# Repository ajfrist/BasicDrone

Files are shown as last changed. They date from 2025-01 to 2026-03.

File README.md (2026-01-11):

# BasicDrone Project

This is a custom-designed Arduino-based drone and controller system that uses a LoRa transceiver for reliable communication. The project includes 3D printed components modeled in Blender and a custom software sketches.

## 🚀 **Project Overview**

This project aims to create an affordable, modular, and easy-to-build drone system. The drone is powered by an Arduino Nano, while the controller uses an Arduino Uno for flight control. Communication between the drone and the controller is handled by a robust LoRa transceiver.

### **Features**
- Arduino Nano-based drone with custom code for optimal motor control and sensor integration.
- Arduino Uno-based controller for user-friendly flight controls.
- LoRa transceiver for long-range wireless communication.
- Blender-designed 3D printed parts for lightweight and customizable drone assembly.

## 🛠️ **Parts List**

### **Drone:**
- Arduino Nano
- LoRa SX1276 transceiver module
- EMAX RS2205 2300kv brushless motor (x4)
- BLHeli LittleBee Electronic Speed Controllers (ESCs) (x4)
- 5' Propellers (x4)
- 3D printed frame components
- Ovonic 3S 50C 2200mAh 11.1V LiPo Battery 
- GY-521 MPU-6050 Gyroscope & Accelerometer
- ArduCAM-2MP-Plus B0067
- Misc: wires, heat shrink tubing

### **Controller:**
- Arduino Uno
- LoRa SX1276 transceiver module 
- Joystick modules (x2)
- Misc: push buttons, resistors, LEDs, wires

## 🧩 **CAD Design & Prototyping**

All 3D models for this project were designed in **Blender**, with an emphasis on simplicity and structural integrity. The designs are optimized for 3D printing using widely accessible filament-based printers. 

### **Prototype Images:**
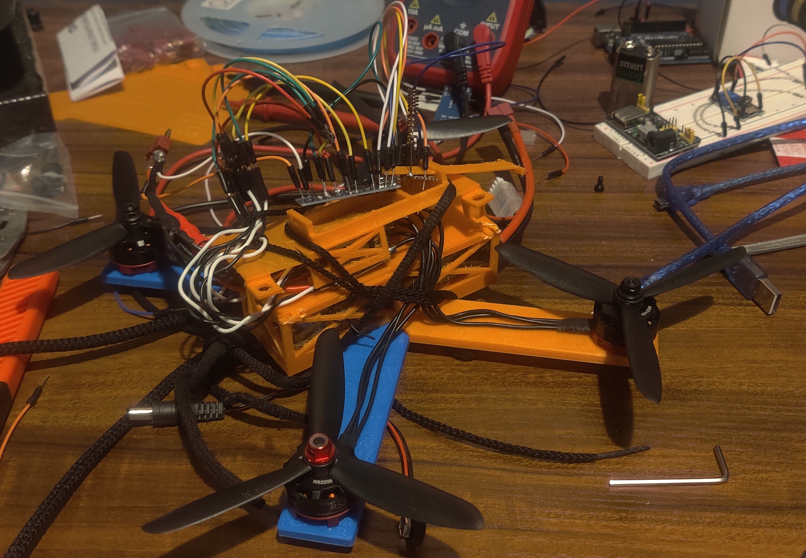
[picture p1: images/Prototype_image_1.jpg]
Prototype Image
**

## ✍️ **Schematics**

The schematics for the drone and the controller detail the electrical connections, ensuring you can replicate the design accurately. 

### Drone
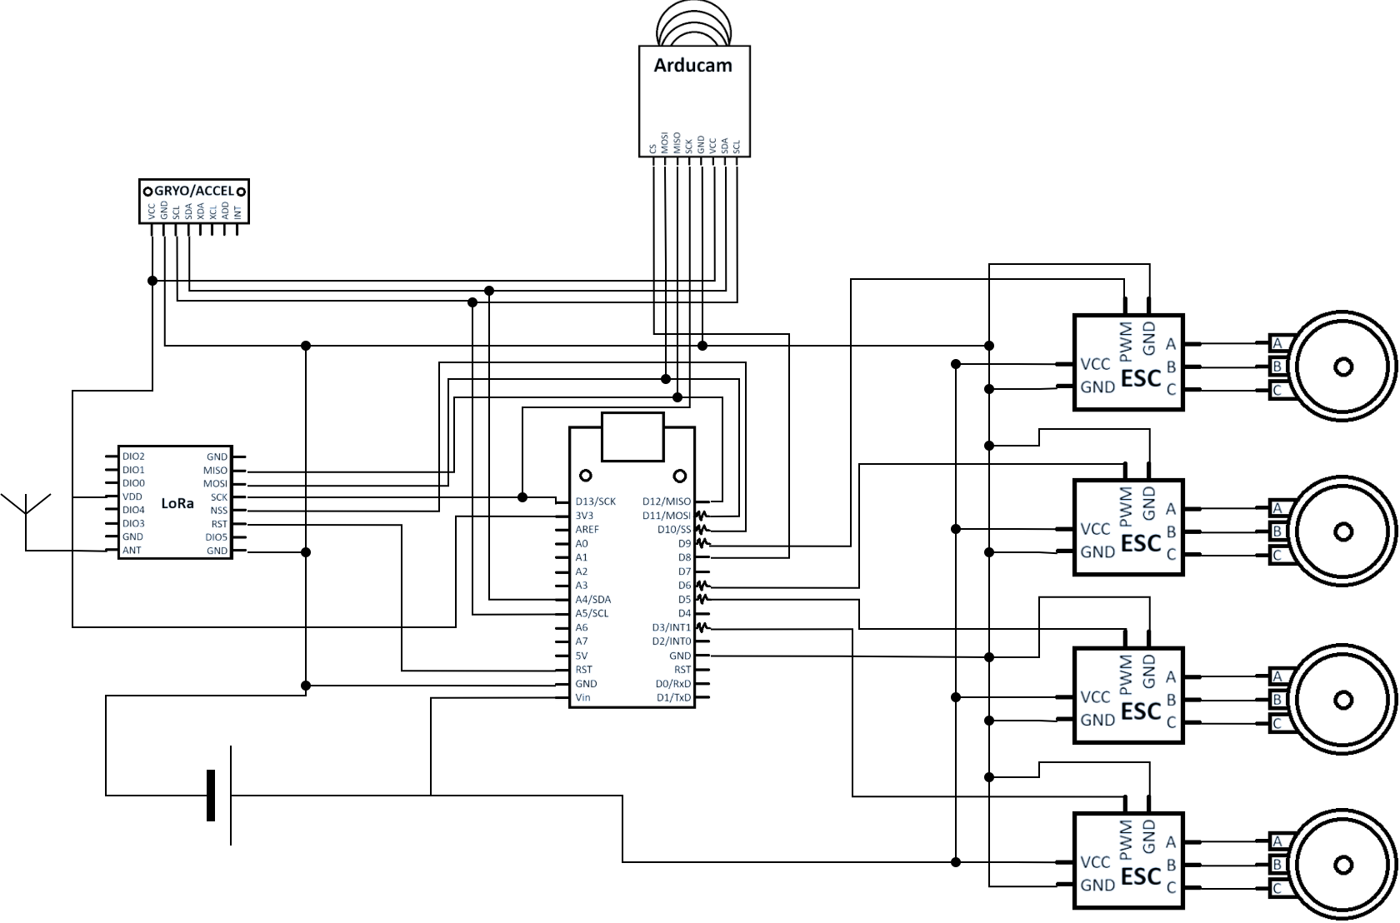
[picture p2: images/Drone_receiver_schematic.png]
Receiver Schematic Image
**

### Controller
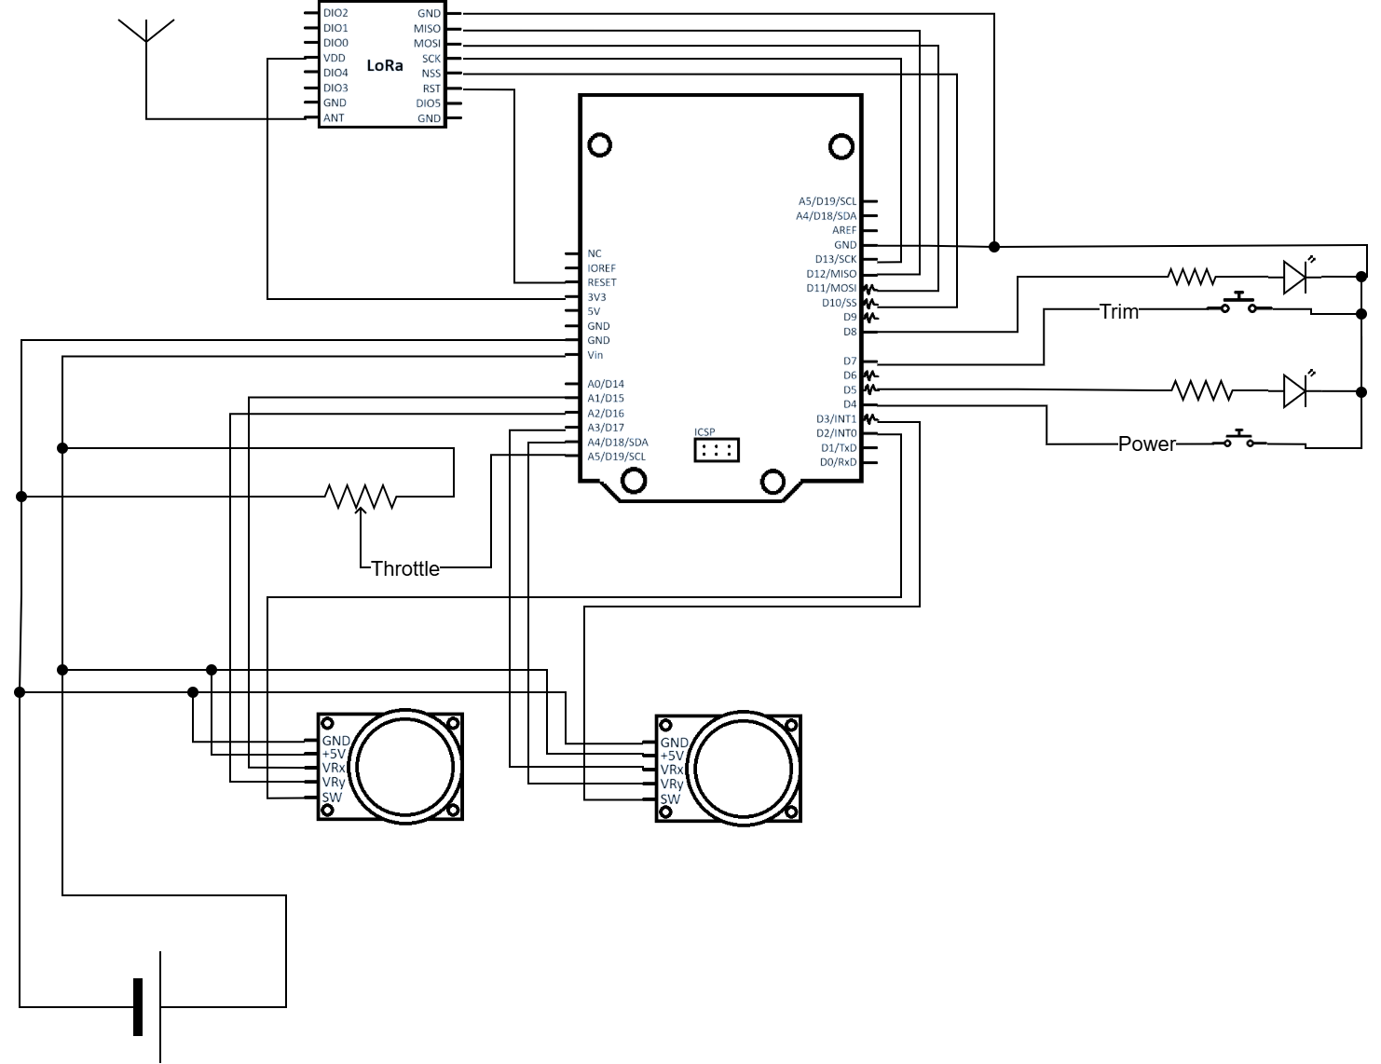
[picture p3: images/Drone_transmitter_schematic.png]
Transmitter Schematic Image
**

## 🎯 **Getting Started**

1. Install the Arduino IDE for uploading the custom code to the boards.
2. Have Blender or another CAD software installed if you wish to modify or customize the 3D models.
3. Ensure access to a 3D printer for building the mechanical components.
4. Total printed items includes:
    - Drone top & bottom
    - 4x pins
    - 2x each of Left/Right Wings (for front and back)
    - Securing bar for Ardunio Nano
5. Flash Arduino Uno with the `drone_transmitter_post` sketch and Arduino Nano with the `drone_receiver_post` sketch.

## 📜 **License**
This project is licensed under the MIT License - see the [LICENSE](LICENSE) file for details.

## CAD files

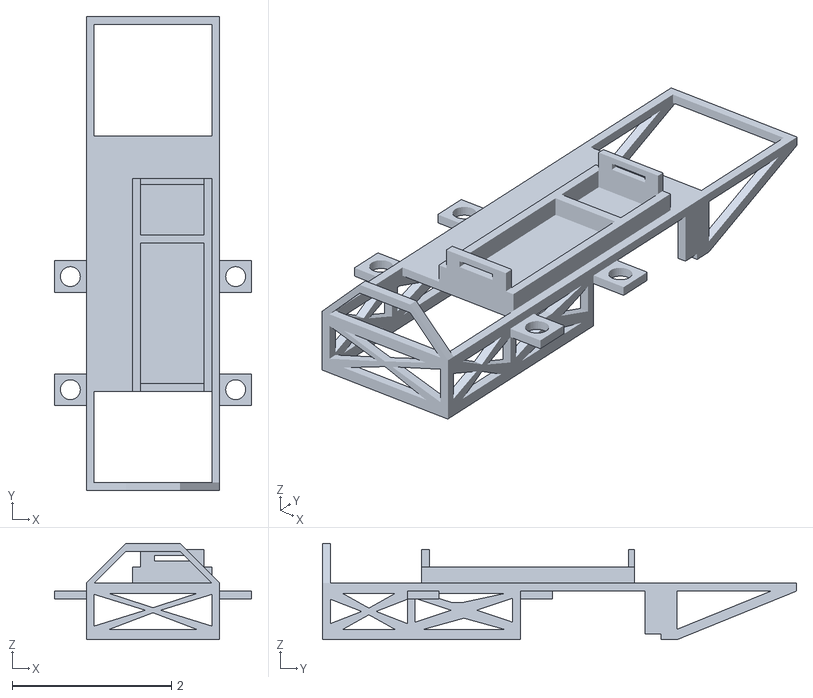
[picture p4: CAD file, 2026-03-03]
stl/Drone_Case_Top.stl
2.48 x 5.95 x 1.21

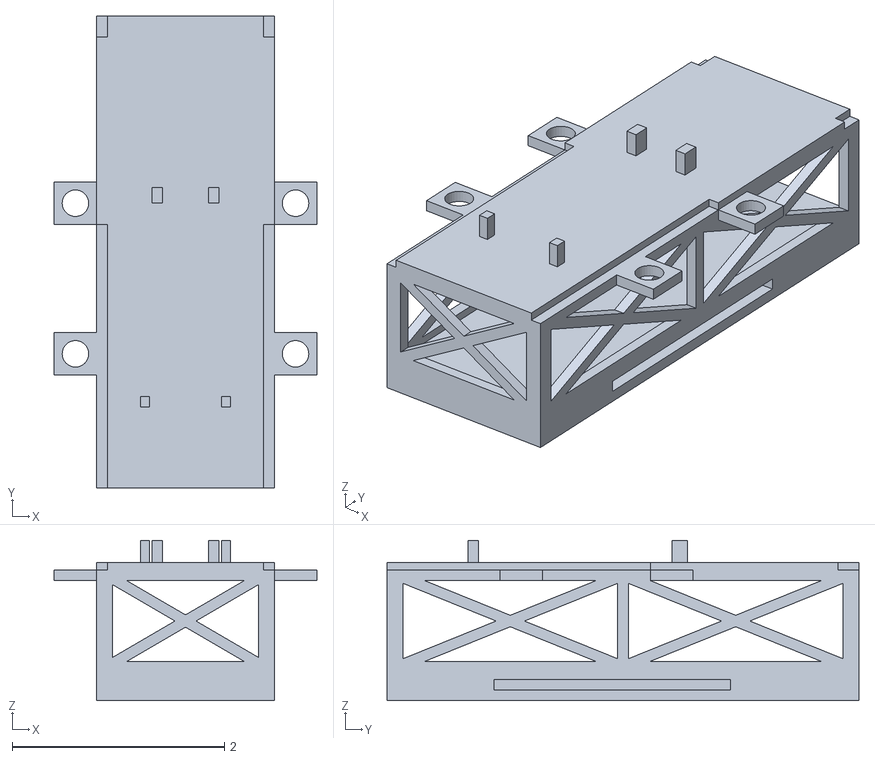
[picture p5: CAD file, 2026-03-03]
stl/Drone_Case_Bottom.stl
2.48 x 4.45 x 1.51

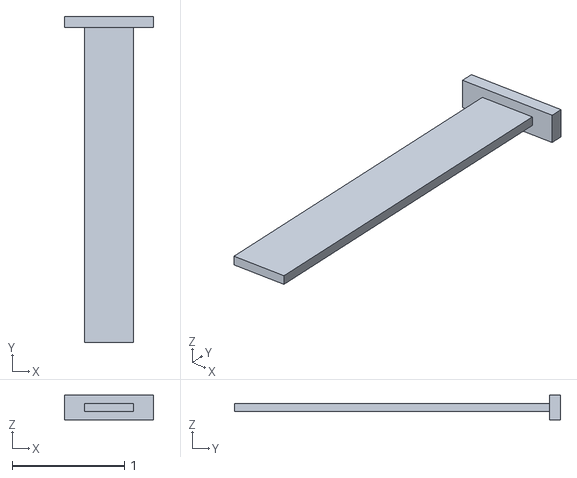
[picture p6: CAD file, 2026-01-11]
stl/Top_Secure.stl
0.792 x 2.91 x 0.219

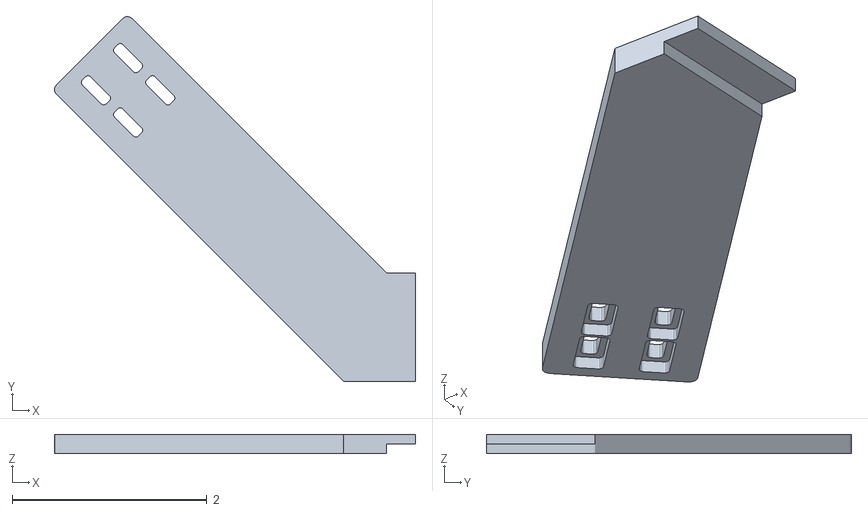
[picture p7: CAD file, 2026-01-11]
stl/Wing_FL.stl
3.71 x 3.75 x 0.2

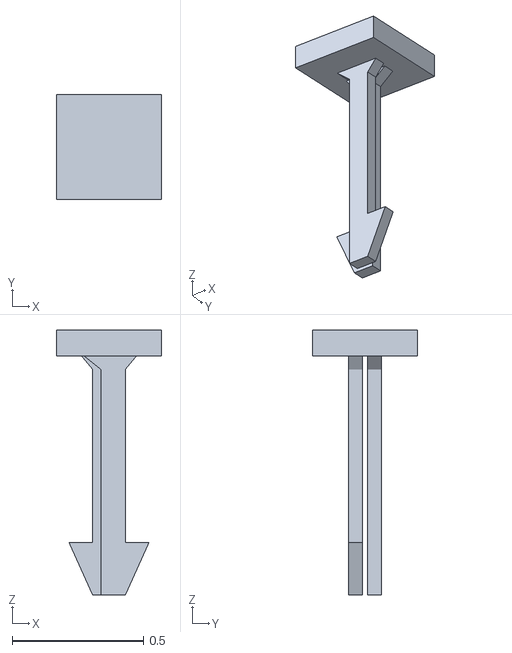
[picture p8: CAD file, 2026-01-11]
stl/Pin_Clip_1.stl
0.4 x 0.4 x 1.01

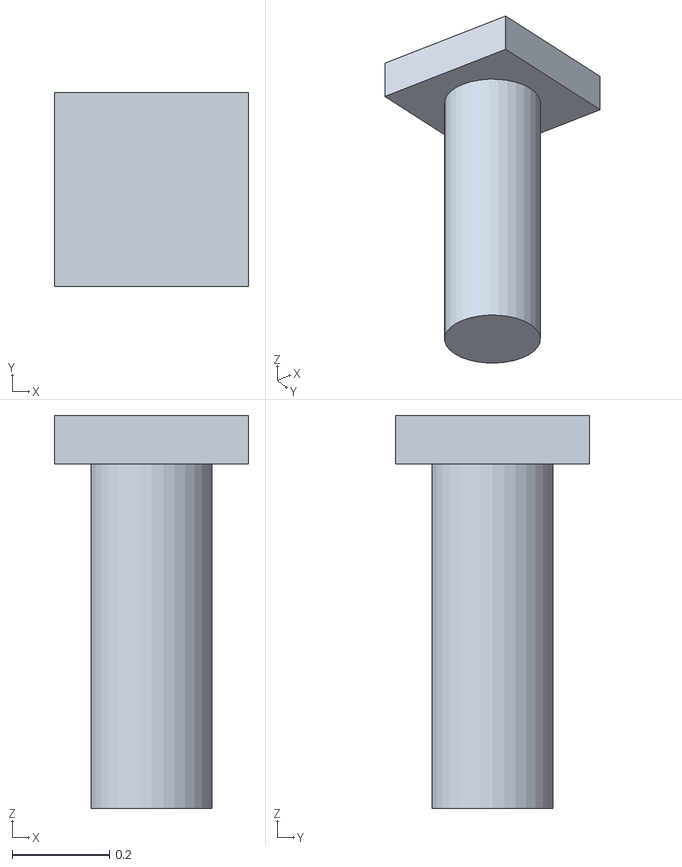
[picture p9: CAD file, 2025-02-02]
stl/Pin_1.stl
0.4 x 0.4 x 0.81

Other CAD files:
stl/Wing_FR.stl
drone_body.blend

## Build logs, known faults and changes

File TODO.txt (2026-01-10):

move inward the vertical supporters
need 4 bars, not two
loop on top front & top back for feeding wire through to prevent falling into side props
side guard not aligned
screw holes - not long enough, too deep

screw measures: 
thread lentgh: .230
thread width: .115
head width .210
head height: .114

screw hole scale x: 1.79167 times      \___ 0.0475 all direction, 0.095 per axis
 		y:  1.2375 times   /
vertically move screw head gap: .09 clearance on bottom, 0.11 rest through to top

Code: 
- transmitter/receiver: adjust LoRa transmit encoding to send using byte encoding not ASCII
- transmitter/receiver: add check bit to ensure packet clarity
- receiver: functionality to adjust movement scalers boundaries according to current trim 

- eventually encode/compress camera feed?

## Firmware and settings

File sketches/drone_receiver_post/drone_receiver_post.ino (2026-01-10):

#include <Servo.h>
#include <SPI.h>
#include <LoRa.h>
// #include <Wire.h> // used for all I2C devices

#define DEBUG 1  // Set to 1 to enable debug prints
#if DEBUG
  #define DEBUG_PRINT(x)    Serial.print(x)
  #define DEBUG_PRINTLN(x)  Serial.println(x)
#else
  #define DEBUG_PRINT(x)    do {} while (0)
  #define DEBUG_PRINTLN(x)  do {} while (0)
#endif

// Memory checking function
#ifdef __arm__
// should use uinstd.h to define sbrk but Due causes a conflict
extern "C" char* sbrk(int incr);
#else  // __ARM__
extern char *__brkval;
#endif  // __arm__

int freeMemory() {
  char top;
#ifdef __arm__
  return &top - reinterpret_cast<char*>(sbrk(0));
#elif defined(CORE_TEENSY) || (ARDUINO > 103 && ARDUINO != 151)
  return &top - __brkval;
#else  // __arm__
  return __brkval ? &top - __brkval : &top - __malloc_heap_start;
#endif  // __arm__
}


double applyDeadzone(int value, int deadzone_radius = 5);

// const int MPU_ADDR = 0x68; // I2C address of the MPU-6050. If AD0 pin is set to HIGH, the I2C address will be 0x69.
// int16_t accelerometer_x, accelerometer_y, accelerometer_z; // variables for accelerometer raw data
// int16_t gyro_x, gyro_y, gyro_z; // variables for gyro raw data
// int16_t temperature; // variables for temperature data
// char tmp_str[7]; // temporary variable used in convert function - used to output data to serial console
// char* convert_int16_to_str(int16_t i) { // converts int16 to string. Moreover, resulting strings will have the same length in the debug monitor.
//   sprintf(tmp_str, "%6d", i);
//   return tmp_str;
// }

Servo motor1;
Servo motor2;
Servo motor3;
Servo motor4;

// int MOTOR_PIN_1 = 1;
// int MOTOR_PIN_2 = 9;
// int MOTOR_PIN_3 = 10;
// int MOTOR_PIN_4 = 13;
const int MOTOR_PIN_1 = 3;
const int MOTOR_PIN_2 = 5;
const int MOTOR_PIN_3 = 6;
const int MOTOR_PIN_4 = 9;


/**
Motor microsecond active value ranges (low/off -> high/max power): 
motor1: ~1100-1900
motor2: ~1100-1900
motor3: ~1100-1900
motor4: ~1100-1900

DEFAULT -> 1000 = OFF
*/

//FIX BASED ON TUNING
// Default, idle (balanced) speeds
const int MOTOR_POWER_1 = 1300;
const int MOTOR_POWER_2 = 1300;
const int MOTOR_POWER_3 = 1300;
const int MOTOR_POWER_4 = 1300;

// State trim settings
int motor_trim_1 = 0;
int motor_trim_2 = 0;
int motor_trim_3 = 0;
int motor_trim_4 = 0;

// Used if lost packet or signal
double last_power1 = MOTOR_POWER_1;
double last_power2 = MOTOR_POWER_2;
double last_power3 = MOTOR_POWER_3;
double last_power4 = MOTOR_POWER_4;
int isOn = 0;


/*
 Motor Configuration:
 2 3
 1 4
 CCW CW
 CW  CCW

 Motor 1: Rear left CW
 Motor 2: Front left CCW
 Motor 3: Front right CW
 Motor 4: Rear right CCW
 */

// Set max bounding for motor movements; keeps joystick values within ms domain
const double THRUST_SCALER = 0.5;
const double FORWARD_MOVEMENT_SCALER = 0.5;
const double SIDE_MOVEMENT_SCALER = 0.5;
const double ROTATION_SCALER = 0.5;


void setup() {
  Serial.begin(9600);
  motor1.attach(MOTOR_PIN_1);
  motor1.writeMicroseconds(1000);
  motor2.attach(MOTOR_PIN_2);
  motor2.writeMicroseconds(1000);
  motor3.attach(MOTOR_PIN_3);
  motor3.writeMicroseconds(1000);
  motor4.attach(MOTOR_PIN_4);
  motor4.writeMicroseconds(1000);

  while (!Serial);
  DEBUG_PRINTLN("LoRa Receiver");
  if (!LoRa.begin(915E6)) {
    DEBUG_PRINTLN("Starting Lora failed!");
    while (1);
  }

  LoRa.receive();

  // // Setup for GY-521 Gyro/Accelerometer
  // Wire.begin();
  // Wire.beginTransmission(MPU_ADDR); // Begins a transmission to the I2C slave (GY-521 board)
  // Wire.write(0x6B); // PWR_MGMT_1 register
  // Wire.write(0); // set to zero (wakes up the MPU-6050)
  // Wire.endTransmission(true);

  delay(15000);
}

void loop() {
  DEBUG_PRINT("Free memory: ");
  DEBUG_PRINTLN(freeMemory());
  // int throttle = (int) LoRa.read();
  // int trimToggle = (int) LoRa.read();
  // int switch2 = (int) LoRa.read();
  // int x1 = (int) LoRa.read();
  // int y1 = (int) LoRa.read();
  // int x2 = (int) LoRa.read();
  // int y2 = (int) LoRa.read();
  int throttle = -1;
  int trimToggle = -1;
  int power = -1;
  int x1 = -1;
  int y1 = -1;
  int x2 = -1;
  int y2 = -1;
  // throttle = (int) LoRa.read();
  // trimToggle = (int) LoRa.read();
  // switch2 = (int) LoRa.read();
  // x1 = (int) LoRa.read();
  // y1 = (int) LoRa.read();
  // x2 = (int) LoRa.read();
  // y2 = (int) LoRa.read();


  // // Retrieve GY-521 Gyro/Accelerometer info
  // Wire.beginTransmission(MPU_ADDR); // access I2C device at listed address
  // Wire.write(0x3B); // starting with register 0x3B (ACCEL_XOUT_H) [MPU-6000 and MPU-6050 Register Map and Descriptions Revision 4.2, p.40]
  // Wire.endTransmission(false); // the parameter indicates that the Arduino will send a restart. As a result, the connection is kept active.
  // Wire.requestFrom(MPU_ADDR, 7*2, true); // request a total of 7*2=14 registers
  
  // // "Wire.read()<<8 | Wire.read();" means two registers are read and stored in the same variable
  // accelerometer_x = Wire.read()<<8 | Wire.read(); // reading registers: 0x3B (ACCEL_XOUT_H) and 0x3C (ACCEL_XOUT_L)
  // accelerometer_y = Wire.read()<<8 | Wire.read(); // reading registers: 0x3D (ACCEL_YOUT_H) and 0x3E (ACCEL_YOUT_L)
  // accelerometer_z = Wire.read()<<8 | Wire.read(); // reading registers: 0x3F (ACCEL_ZOUT_H) and 0x40 (ACCEL_ZOUT_L)
  // temperature = Wire.read()<<8 | Wire.read(); // reading registers: 0x41 (TEMP_OUT_H) and 0x42 (TEMP_OUT_L)
  // gyro_x = Wire.read()<<8 | Wire.read(); // reading registers: 0x43 (GYRO_XOUT_H) and 0x44 (GYRO_XOUT_L)
  // gyro_y = Wire.read()<<8 | Wire.read(); // reading registers: 0x45 (GYRO_YOUT_H) and 0x46 (GYRO_YOUT_L)
  // gyro_z = Wire.read()<<8 | Wire.read(); // reading registers: 0x47 (GYRO_ZOUT_H) and 0x48 (GYRO_ZOUT_L)
  
  // // print out data
  // Serial.print("aX = "); Serial.print(convert_int16_to_str(accelerometer_x));
  // Serial.print(" | aY = "); Serial.print(convert_int16_to_str(accelerometer_y));
  // Serial.print(" | aZ = "); Serial.print(convert_int16_to_str(accelerometer_z));
  // // the following equation was taken from the documentation [MPU-6000/MPU-6050 Register Map and Description, p.30]
  // Serial.print(" | temp = "); Serial.print(temperature/340.00+36.53);
  // Serial.print(" | gX = "); Serial.print(convert_int16_to_str(gyro_x));
  // Serial.print(" | gY = "); Serial.print(convert_int16_to_str(gyro_y));
  // Serial.print(" | gZ = "); Serial.print(convert_int16_to_str(gyro_z));
  // Serial.println();
  

    
  // try to parse packet (extra packets?)
  int packetSize = LoRa.parsePacket();
  // DEBUG_PRINT("packet size: ");
  // DEBUG_PRINTLN(packetSize);
  if (packetSize) {
    // read packet
    DEBUG_PRINT("Received packet '");

    // read packet
    // while (int x = LoRa.available() > 0) {
    //   // DEBUG_PRINTLN((char)LoRa.read());
    //   DEBUG_PRINTLN(x);
      
      // String buffer = "";
      // char c = (char) LoRa.read();
      // while (c != '_'){
      //   buffer += c;
      //   c = (char) LoRa.read();
      // }
      // DEBUG_PRINT("String: ");
      // DEBUG_PRINTLN(buffer);
      DEBUG_PRINTLN("-");
      DEBUG_PRINTLN(freeMemory());
      throttle =  readToInt();
      DEBUG_PRINTLN(freeMemory());
      trimToggle = readToInt();
      DEBUG_PRINTLN(freeMemory());
      power = readToInt();
      DEBUG_PRINTLN(freeMemory());
      x1 = readToInt();
      DEBUG_PRINTLN(freeMemory());
      y1 = readToInt(); // 1
      DEBUG_PRINTLN(freeMemory());
      x2 = readToInt();
      DEBUG_PRINTLN(freeMemory());
      y2 = readToInt(); // 1,1
      DEBUG_PRINTLN(freeMemory());
      DEBUG_PRINTLN("-");

    // }
    DEBUG_PRINTLN("end");
    // while (LoRa.available()) {

      // throttle = (int) LoRa.read();
      // trimToggle = (int) LoRa.read();
      // switch2 = (int) LoRa.read();
      // x1 = (int) LoRa.read();
      // y1 = (int) LoRa.read();
      // x2 = (int) LoRa.read();
      // y2 = (int) LoRa.read();
    // }
  }
  DEBUG_PRINT("Throttle: ");
  DEBUG_PRINTLN(throttle);
  DEBUG_PRINT("Trim Toggle: ");
  DEBUG_PRINTLN(trimToggle);
  DEBUG_PRINT("Power: ");
  DEBUG_PRINTLN(power);
  DEBUG_PRINT("x1: ");
  DEBUG_PRINTLN(x1);
  DEBUG_PRINT("y1: ");
  DEBUG_PRINTLN(y1);
  DEBUG_PRINT("x2: ");
  DEBUG_PRINTLN(x2);
  DEBUG_PRINT("y2: ");
  DEBUG_PRINTLN(y2);

  int receivedRssi = LoRa.packetRssi();

  // If not -1, then packet was received
  if (throttle == -1 || trimToggle == -1 || power == -1 || x1 == -1 || y1 == -1 || x2 == -1 || y2 == -1){ 
    DEBUG_PRINTLN("No transmitted data received");
    // motor1.writeMicroseconds(last_power1);
    // motor2.writeMicroseconds(last_power2);
    // motor3.writeMicroseconds(last_power3);
    // motor4.writeMicroseconds(last_power4);
    return; 
  }

  // If less than 0, then corrupted transmission - can be combined with above, but for now is explicit statement for testing purposes
  if (throttle <= -1 || trimToggle <= -1 || power <= -1 || x1 <= -1 || y1 <= -1 || x2 <= -1 || y2 <= -1){ 
    DEBUG_PRINTLN("Corrupted data received, returning.");
    return; 
  }

  // Check if power switched on
  if (power != -1){
    isOn = power;
  }
  // If powered off, turn motors off (1000 us)
  if (isOn == 0){
    DEBUG_PRINTLN("Power switch not enabled on transmitter.");
    motor1.writeMicroseconds(1000);
    motor2.writeMicroseconds(1000);
    motor3.writeMicroseconds(1000);
    motor4.writeMicroseconds(1000);
    return;
  }

  // Calculcate current iteration motor power amounts
  double power1 = 0;
  double power2 = 0;
  double power3 = 0;
  double power4 = 0;

  // If not trimming 
  if (trimToggle == 0){
    //vertical ascent management
    power1 += (applyDeadzone(y1) - 511) * THRUST_SCALER * throttle / 1023;
    power2 += (applyDeadzone(y1) - 511) * THRUST_SCALER * throttle / 1023;
    power3 += (applyDeadzone(y1) - 511) * THRUST_SCALER * throttle / 1023;
    power4 += (applyDeadzone(y1) - 511) * THRUST_SCALER * throttle / 1023;

    //forward/backwards movement
    power1 += (applyDeadzone(y2) - 511) * FORWARD_MOVEMENT_SCALER * throttle / 1023;
    power2 -= (applyDeadzone(y2) - 511) * FORWARD_MOVEMENT_SCALER * throttle / 1023;
    power3 -= (applyDeadzone(y2) - 511) * FORWARD_MOVEMENT_SCALER * throttle / 1023;
    power4 += (applyDeadzone(y2) - 511) * FORWARD_MOVEMENT_SCALER * throttle / 1023;

    //left/right movement
    power1 += (applyDeadzone(x2) - 511) * SIDE_MOVEMENT_SCALER * throttle / 1023;
    power2 += (applyDeadzone(x2) - 511) * SIDE_MOVEMENT_SCALER * throttle / 1023;
    power3 -= (applyDeadzone(x2) - 511) * SIDE_MOVEMENT_SCALER * throttle / 1023;
    power4 -= (applyDeadzone(x2) - 511) * SIDE_MOVEMENT_SCALER * throttle / 1023;

    //rotation 
    power1 -= (applyDeadzone(x1) - 511) * ROTATION_SCALER * throttle / 1023;
    power2 += (applyDeadzone(x1) - 511) * ROTATION_SCALER * throttle / 1023;
    power3 -= (applyDeadzone(x1) - 511) * ROTATION_SCALER * throttle / 1023;
    power4 += (applyDeadzone(x1) - 511) * ROTATION_SCALER * throttle / 1023;
  }
  // Trimming mode
  else if (trimToggle == 1){
    // Trim vertical ascent
    if (y1 > 511){ // up
      motor_trim_1 += 10;
      motor_trim_2 += 10;
      motor_trim_3 += 10;
      motor_trim_4 += 10;
    } 
    else if (y1 < 511){ // down
      motor_trim_1 -= 10;
      motor_trim_2 -= 10;
      motor_trim_3 -= 10;
      motor_trim_4 -= 10;
    }
    // Trim forward/backwards movement
    if (y2 > 511){ // forward
      motor_trim_1 += 10;
      motor_trim_2 -= 10;
      motor_trim_3 -= 10;
      motor_trim_4 += 10;
    } 
    else if (y2 < 511){ // backward
      motor_trim_1 -= 10;
      motor_trim_2 += 10;
      motor_trim_3 += 10;
      motor_trim_4 -= 10;
    }
    // Trim left/right movement
    if (x2 > 511){ // right
      motor_trim_1 += 10;
      motor_trim_2 += 10;
      motor_trim_3 -= 10;
      motor_trim_4 -= 10;
    } 
    else if (x2 < 511){ // left
      motor_trim_1 -= 10;
      motor_trim_2 -= 10;
      motor_trim_3 += 10;
      motor_trim_4 += 10;
    }
    // Trim rotation
    if (x1 > 511){ // CW
      motor_trim_1 -= 10;
      motor_trim_2 += 10;
      motor_trim_3 -= 10;
      motor_trim_4 += 10;
    } 
    else if (x1 < 511){ // CCW
      motor_trim_1 += 10;
      motor_trim_2 -= 10;
      motor_trim_3 += 10;
      motor_trim_4 -= 10;
    }    
  }

  // Add idle speed to motor powers
  power1 += MOTOR_POWER_1 + motor_trim_1;
  power2 += MOTOR_POWER_2 + motor_trim_2;
  power3 += MOTOR_POWER_3 + motor_trim_3;
  power4 += MOTOR_POWER_4 + motor_trim_4;

  
  // Only write to motors if value has changed since last loop - shouldn't need to continuously update
  if (abs(last_power1-power1)<0.001){
    motor1.writeMicroseconds((int) power1);
  }
  if (abs(last_power2-power2)<0.001){
    motor2.writeMicroseconds((int) power2);
  }
  if (abs(last_power3-power3)<0.001){
    motor3.writeMicroseconds((int) power3);
  }
  if (abs(last_power4-power4)<0.001){
    motor4.writeMicroseconds((int) power4);
  }
  last_power1 = power1;
  last_power2 = power2;
  last_power3 = power3;
  last_power4 = power4;

  // Debug print motor powers to console
  DEBUG_PRINT("Motor powers: ");
  DEBUG_PRINT(power1);
  DEBUG_PRINT(" ");
  DEBUG_PRINT(power2);
  DEBUG_PRINT(" ");
  DEBUG_PRINT(power3);
  DEBUG_PRINT(" ");
  DEBUG_PRINT(power4);
  DEBUG_PRINTLN();
  #if DEBUG
  #else
  Serial.print("Motor powers: ");
  Serial.print(power1);
  Serial.print(" ");
  Serial.print(power2);
  Serial.print(" ");
  Serial.print(power3);
  Serial.print(" ");
  Serial.print(power4);
  Serial.println();
  #endif
  
  
  // // Return detected received data
  // LoRa.beginPacket();
  // LoRa.write(throttle);
  // // LoRa.write(motorBitmask);
  // // LoRa.write(MOTOR_POWER_1);
  // // LoRa.write(MOTOR_POWER_2);
  // // LoRa.write(MOTOR_POWER_3);
  // // LoRa.write(MOTOR_POWER_4);
  // LoRa.write(power1);
  // LoRa.write(power2);
  // LoRa.write(power3);
  // LoRa.write(power4);
  // LoRa.write(receivedRssi);
  // LoRa.endPacket();
  
  // DEBUG_PRINTLN("Packet sent");
}

// Negative if failed reading: invalid packet
int readToInt(){
  DEBUG_PRINT("read:");
  String buffer = "";
  DEBUG_PRINT("-");
  char c = (char) LoRa.read();
  DEBUG_PRINT("-");
  DEBUG_PRINT("\'");
  DEBUG_PRINT((int)c);
  DEBUG_PRINT("\'");
  while (c != '_' && c >= 0){
    DEBUG_PRINT("1");
    buffer += c;
    DEBUG_PRINT("2");
    c = (char) LoRa.read();
    DEBUG_PRINT("3");
    DEBUG_PRINT("\'");
    DEBUG_PRINT((int)c);
    DEBUG_PRINT("\'");
  }
  DEBUG_PRINTLN("-");
  if (c < 0){
    DEBUG_PRINTLN("\n\nTESTING RESTART...");
    //delay(5000);
    return c;
  }
  return buffer.toInt();
}

/*
 Applies cushion around neutral joystick to account for drift & slight unintentional movements.
 Neutralizes values in deadzone and scales remaining values within [0, 1023].
 @params:
 int value - joystick value to be mapped;
 int deadzone_radius - radius of effect of the joystick deadzone;
 */
double applyDeadzone(int value, int deadzone_radius){

  // Apply zone around center (511, 511)
  if (abs(value - 511) <= deadzone_radius){
    return 511;
  } else {
    if (value > 511){ // value > 511 + deadzone
      return (double) map(value, 511, 1023, 511+deadzone_radius, 1023);
    } else { // value < 511 - deadzone
      return (double) map(value, 0, 511, 0, 511-deadzone_radius);
    }
  }
}

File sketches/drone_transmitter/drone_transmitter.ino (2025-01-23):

#include <SPI.h>
#include <LoRa.h>

int LED_PIN_1 = 18;
int LED_PIN_2 = 19;
int LED_PIN_3 = 2;
int LED_PIN_4 = 3;

//int INCREASE_INPUT_PIN = 4;
//int DECREASE_INPUT_PIN = 5;
int MOTOR_TOGGLE_PIN_1 = 4;
int MOTOR_TOGGLE_PIN_2 = 5;
int MOTOR_TOGGLE_PIN_3 = 6;
int MOTOR_TOGGLE_PIN_4 = 7;

int THROTTLE_PIN = A5;

int motorActive1 = 0;
int motorActive2 = 0;
int motorActive3 = 0;
int motorActive4 = 0;

int initialThrottle = 0;
int throttle = 0;
int throttleBuffer = 30;
bool pressed = false;

void setup() {
  // Init pins 1,2,3,4; set to default on technically 
  pinMode(LED_PIN_1, OUTPUT);
  pinMode(LED_PIN_2, OUTPUT);
  pinMode(LED_PIN_3, OUTPUT);
  pinMode(LED_PIN_4, OUTPUT);
  digitalWrite(LED_PIN_1, LOW);
  digitalWrite(LED_PIN_2, LOW);
  digitalWrite(LED_PIN_3, LOW);
  digitalWrite(LED_PIN_4, LOW);
  pinMode(MOTOR_TOGGLE_PIN_1, INPUT_PULLUP);
  pinMode(MOTOR_TOGGLE_PIN_2, INPUT_PULLUP);
  pinMode(MOTOR_TOGGLE_PIN_3, INPUT_PULLUP);
  pinMode(MOTOR_TOGGLE_PIN_4, INPUT_PULLUP);
  pinMode(THROTTLE_PIN, INPUT);

  initialThrottle = analogRead(THROTTLE_PIN);
  throttle = initialThrottle;
  
  Serial.begin(9600);
//  while (!Serial);
//  
//  Serial.println("LoRa Sender");
//  if (!LoRa.begin(915E6)) {
//    Serial.println("Starting Lora failed!");
//    while (1);
//  }
}

void loop() {
  // Read each button state for toggling trim
  int toggle1 = digitalRead(MOTOR_TOGGLE_PIN_1);
  int toggle2 = digitalRead(MOTOR_TOGGLE_PIN_2);
  int toggle3 = digitalRead(MOTOR_TOGGLE_PIN_3);
  int toggle4 = digitalRead(MOTOR_TOGGLE_PIN_4);

  // Toggle each motor's active state based on if pressed
  if (!toggle1 and not pressed){ // HIGH == off, LOW == on
    pressed = true;
    motorActive1 = !motorActive1;
  }
  else if (!toggle2){
    pressed = true;
    motorActive2 = !motorActive2;
  }
//  Serial.println(toggle);
  else if (!toggle3){
    pressed = true;
    motorActive3 = !motorActive3;
  }
  else if (!toggle4){
    pressed = true;
    motorActive4 = !motorActive4;
  }
  if (toggle1 and toggle2 and toggle3 and toggle4){
    pressed = false;
  }
  // Turn on LED light indicating state of active motor toggle value
  digitalWrite(LED_PIN_1, motorActive1);
  digitalWrite(LED_PIN_2, motorActive2);
  digitalWrite(LED_PIN_3, motorActive3);
  digitalWrite(LED_PIN_4, motorActive4);


  // Serial DEBUG info to computer Serial monitor for button states
  Serial.println("*** TRIM RECEIVER ***");
  Serial.print(analogRead(MOTOR_TOGGLE_PIN_1)+", ");
  Serial.print(analogRead(MOTOR_TOGGLE_PIN_2)+", ");
  Serial.print(analogRead(MOTOR_TOGGLE_PIN_3)+", ");
  Serial.println(analogRead(MOTOR_TOGGLE_PIN_4));
  

  // Transmit active motor and trim amount information
  LoRa.beginPacket();

  // Get current throttle position; if abs > threshold, start tracking
  throttle = analogRead(THROTTLE_PIN);
  // if (throttle > initialThrottle){
  //   throttle -= throttleBuffer;
  // } else {
  //   throttle += throttleBuffer;
  // }
  

  // Map trim value to (-10,10) if throttle exceeds buffer threshold, otherwise -100
  int motorThrottle1, motorThrottle2, motorThrottle3, motorThrottle4 = 0;
  if (motorActive1){
    if (throttle > initialThrottle + throttleBuffer){
      motorThrottle1 = map(throttle, 1023-(initialThrottle+30)*2, 1023, -10, 10);
      LoRa.write(motorThrottle1);
    } else if (throttle < initialThrottle - throttleBuffer){
      motorThrottle1 = map(throttle, 1023-(initialThrottle-30)*2, 1023, -10, 10)
      LoRa.write(motorThrottle1);
    }
  } else {LoRa.write(-100);}

  if (motorActive2){
    if (throttle > initialThrottle + throttleBuffer){
      motorThrottle2 = map(throttle, 1023-(initialThrottle+30)*2, 1023, -10, 10);
      LoRa.write(motorThrottle2);
    } else if (throttle < initialThrottle - throttleBuffer){
      motorThrottle2 = map(throttle, 1023-(initialThrottle-30)*2, 1023, -10, 10)
      LoRa.write(motorThrottle2);
    }
  } else {LoRa.write(-100);}

  if (motorActive3){
    if (throttle > initialThrottle + throttleBuffer){
      motorThrottle3 = map(throttle, 1023-(initialThrottle+30)*2, 1023, -10, 10);
      LoRa.write(motorThrottle3);
    } else if (throttle < initialThrottle - throttleBuffer){
      motorThrottle3 = map(throttle, 1023-(initialThrottle-30)*2, 1023, -10, 10)
      LoRa.write(motorThrottle3);
    }
  } else {LoRa.write(-100);}

  if (motorActive4){
    if (throttle > initialThrottle + throttleBuffer){
      motorThrottle4 = map(throttle, 1023-(initialThrottle+30)*2, 1023, -10, 10);
      LoRa.write(motorThrottle4);
    } else if (throttle < initialThrottle - throttleBuffer){
      motorThrottle4 = map(throttle, 1023-(initialThrottle-30)*2, 1023, -10, 10)
      LoRa.write(motorThrottle4);
    }
  } else {LoRa.write(-100);}
  
  // if(motorActive1 and abs(throttle - initialThrottle) > throttleBuffer){
  //   LoRa.write(map(throttle, 1023-initialThrottle*2, 1023, -10, 10));
  // } else {LoRa.write(-100);}

  // if(motorActive2 and abs(throttle - initialThrottle) > throttleBuffer){
  //   LoRa.write(map(throttle, 1023-initialThrottle*2, 1023, -10, 10));
  // } else {LoRa.write(-100);}

  // if(motorActive3 and abs(throttle - initialThrottle) > throttleBuffer){
  //   LoRa.write(map(throttle, 1023-initialThrottle*2, 1023, -10, 10));
  // } else {LoRa.write(-100);}

  // if(motorActive4 and abs(throttle - initialThrottle) > throttleBuffer){
  //   LoRa.write(map(throttle, 1023-initialThrottle*2, 1023, -10, 10));
  // } else {LoRa.write(-100);}  

  LoRa.endPacket();


  // More Serial DEBUG info
  Serial.print(motorThrottle1+", ");
  Serial.print(motorThrottle2+", ");
  Serial.print(motorThrottle3+", ");
  Serial.println(motorThrottle4+", ");
  


  int packetSize = LoRa.parsePacket();
  if (packetSize) {
    // received a packet
    Serial.println("  Received packet: ");

    // read packet
    while (LoRa.available()) {
      Serial.print("Throttle trim adjustment: ");
      int val = (int) LoRa.read();
      Serial.println(val);
      
      Serial.print("Motors adjusted: ");
      val = (int) LoRa.read();
      if (val & 0b0001){
        Serial.print("1 ");
      }
      if (val & 0b0010){
        Serial.print("2 ");
      }
      if (val & 0b0100){
        Serial.print("3 ");
      }
      if (val & 0b1000){
        Serial.print("4 ");
      }
      Serial.println("");

      Serial.print("Current respective throttles: ");
      Serial.print((int)LoRa.read());
      Serial.print((int)LoRa.read());
      Serial.print((int)LoRa.read());
      Serial.println((int)LoRa.read());

      Serial.print("Receiver RSSI: ");
      val = (int) LoRa.read();
      Serial.print(val);
    }
      
    Serial.print(", Transmitter RSSI: ");
    Serial.println(LoRa.packetRssi());
    Serial.println("");
  }
  else {
  //    Serial.println("---no packet---");
  //    Serial.println(analogRead(THROTTLE_PIN));
  }
      

      print RSSI of packet
    Serial.print("' with RSSI ");
    Serial.println(LoRa.packetRssi());

  // Delay 500 ms
  delay(500);
  
}

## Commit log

2025-01-02 First commit: import all files from old computer, and small changes (adding comments code, brush up)
    [drone_body.blend]
2025-01-23 change drone_body.blend files to more recent updated version
    [drone_body.blend]
2025-02-01 midway transition: prior to remove top part's bottom
    [drone_body.blend]
2025-02-02 printing ready
    [Drone_Case_Bottom.stl, Drone_Case_Top.stl, Pin_1.stl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]
2025-07-06 assmebled, functioning code
    [Drone_Case_Bottom.stl, Drone_Case_Top.stl]
2026-01-08 partial modify of screw holes
    [drone_body.blend]
2026-01-08 finish modify screw holes
    [drone_body.blend]
2026-01-10 updated drone schematics, adjusted code to match pinouts & future gryo usage
2026-01-10 added walls on top
    [drone_body.blend]
2026-01-11 moved inward the vertical clamps, added loops for containing stray wires
    [drone_body.blend]
2026-01-11 cleaned up model, exported stl
    [Drone_Case_Bottom.stl, Drone_Case_Top.stl, Pin_Clip_1.stl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]
2026-01-11 updated README, added license, reorganized repo
    [Drone_Case_Bottom.stl, Drone_Case_Top.stl, Pin_1.stl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]
2026-03-03 Fixed model inside, holes, duplicate faces
    [Drone_Case_Bottom.stl, Drone_Case_Top.stl, drone_body.blend]
